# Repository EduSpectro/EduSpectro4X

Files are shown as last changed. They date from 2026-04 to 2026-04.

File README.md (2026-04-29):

# EduSpectro4X
ファームウェア・電子回路
[📖 総合ガイド（Webサイト）はこちら](https://eduspectro.github.io/)

*   **概要**: 「RP2350とC12880MAを組み合わせた分光器の心臓部です」
*   **分光性能諸元**:
    *   測定波長範囲: 340 nm 〜 850 nm（紫外線〜可視光〜近赤外線）
    *   物理画素数: 288 画素（センサー本来の受光素子数）
    *   論理出力点数: 1149 点（4倍オーバーサンプリング間）
    *   波長分解能 (FWHM): 約 10 nm 〜 15 nm
    *   階調分解能: 16bit相当（12bit ADC × 10回累積処理）
    *   最短露光時間: 20 ms（0.02秒）
    *   データ更新間隔: 約 20 ms 〜（露光設定に依存）
*   **特徴**: PIOによる高速制御、10回累積計測してによるノイズ軽減、Catmull-Rom補間など。
*   **必要な環境**:
    *   Arduino IDEのバージョン1.8.19
    *   導入が必要なボードマネージャー（Raspberry Pi Pico/RP2350）
    *   ボード：Waveshare RP2350 Zero、
*   **ハードウェアについて**:
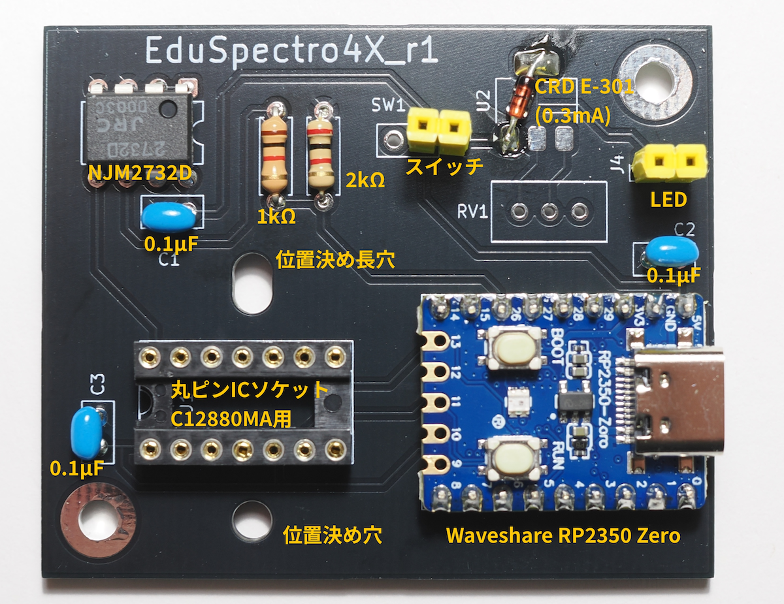
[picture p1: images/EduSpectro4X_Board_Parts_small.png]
EduSpectro基板部品説明
 <dr>

    *   部品リスト：マイコンボード Waveshare RP2350 Zero、分光センサー C12880MA、オペアンプ NJM2732D、0.3mA定電流素子、セラミックコンデンサ 0.1μF(3個)、1kΩ、2kΩ、トグルスイッチ、14ピンICソケット（丸ピン）、ロープロファイルピンヘッダー（オス）、ヘッダーピン(メス)、L型ピンヘッダ（オス）

*   **分光センサー底面と丸ピンICソケットの接触について**:
    *   分光センサーと丸ピンICソケットの間に絶縁シートを挟む。
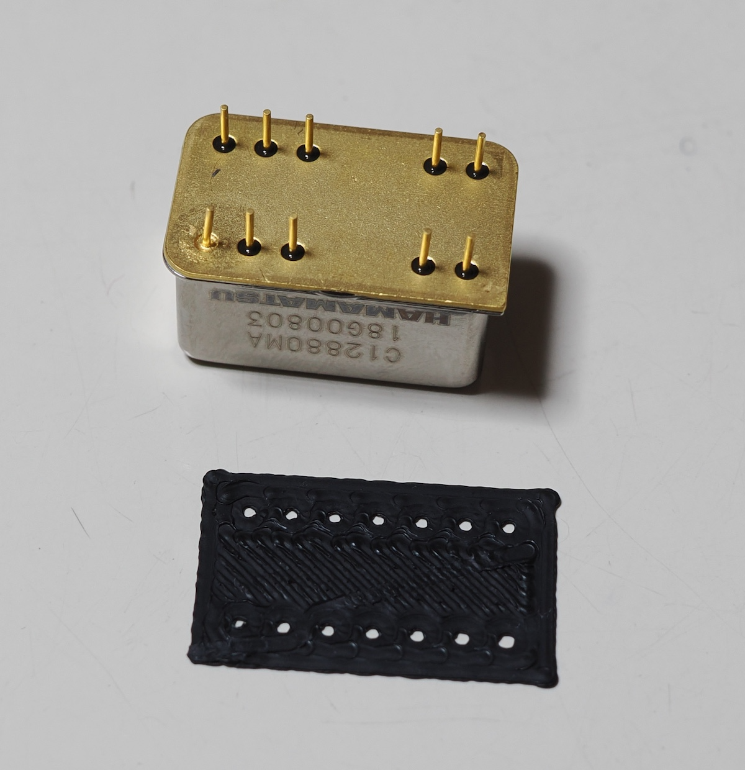
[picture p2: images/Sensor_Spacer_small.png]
センサーと絶縁シート
 <dr>
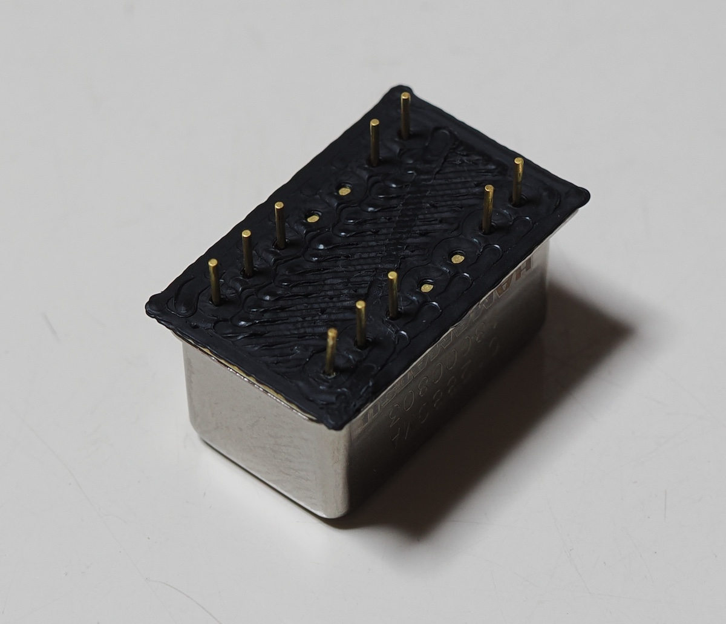
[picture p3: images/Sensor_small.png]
センサーにつける
 <dr>
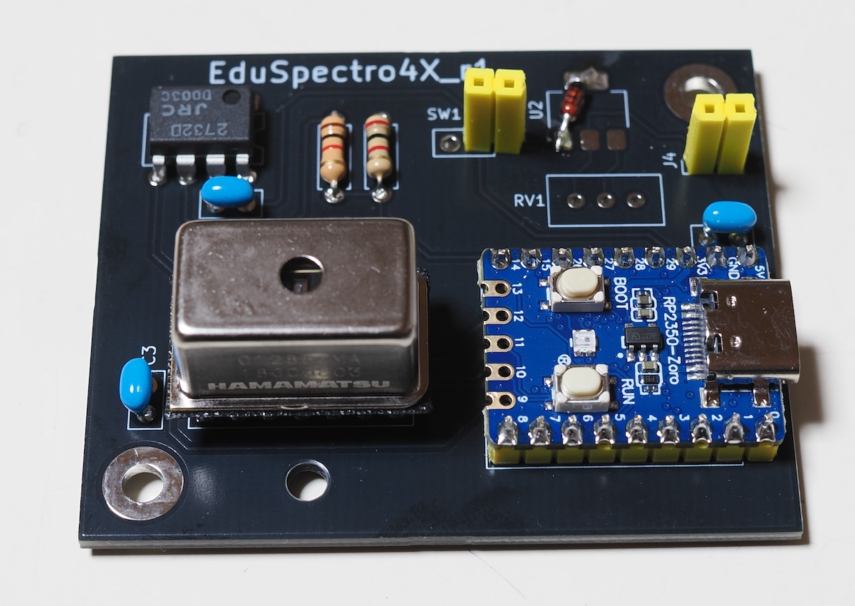
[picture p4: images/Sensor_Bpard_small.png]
センサーを取り付ける
 <dr>

*   **分光センサーのシリアル番号と波長校正データについて**:
    *   ファームウェアでは波長校正は行なっていません。測定・解析アプリケーションEduSpectroLabの"system_config_do_not_delete"フォルダーの"calibration_coefficients.txt"に使っているセンサーのシリアル番号とデータを書き込む必要があります。

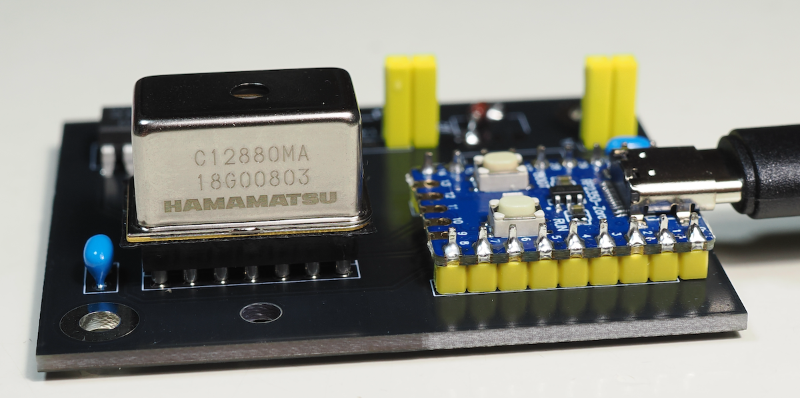
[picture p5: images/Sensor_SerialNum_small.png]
シリアル番号
 <dr>
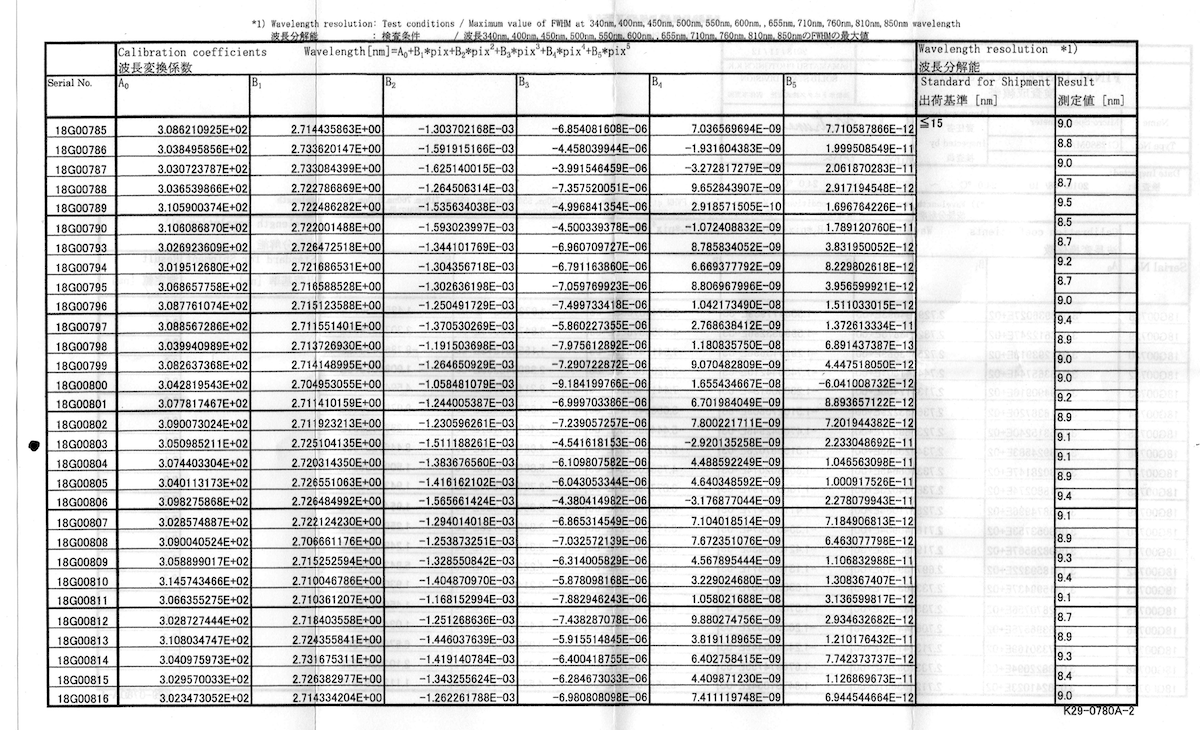
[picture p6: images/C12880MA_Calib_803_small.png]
波長校正データ
 <dr>

*   [KiCadの使い方について](docs/HowToMakePCB_KiCad×GeminiAI.pdf)<br>
*   **使い方**:
*   [Arduino IDEでの書き込み方](docs/ArduinoIDE_Write_Firm.pdf)
*   Raspberry Pi Pico2などのWebでの記事も参照してください。

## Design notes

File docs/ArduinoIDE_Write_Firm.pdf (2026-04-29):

# Arduino IDEでのファームウェアの書き込み

## Mac（15.4）の場合

Arduino IDEは1.8.19を使います。EduSpectro4X.inoを開きます。

Waveshare RP2350-Zeroのボードを使うので、ボードマネージャーでRP2350マイコン用をイ ンストールします。検索窓でRP2350で見つかりました。
Waveshare RP2350 Zeroボードを選択してUSBケーブルを接続するとUF2 Boardが選択されま した。

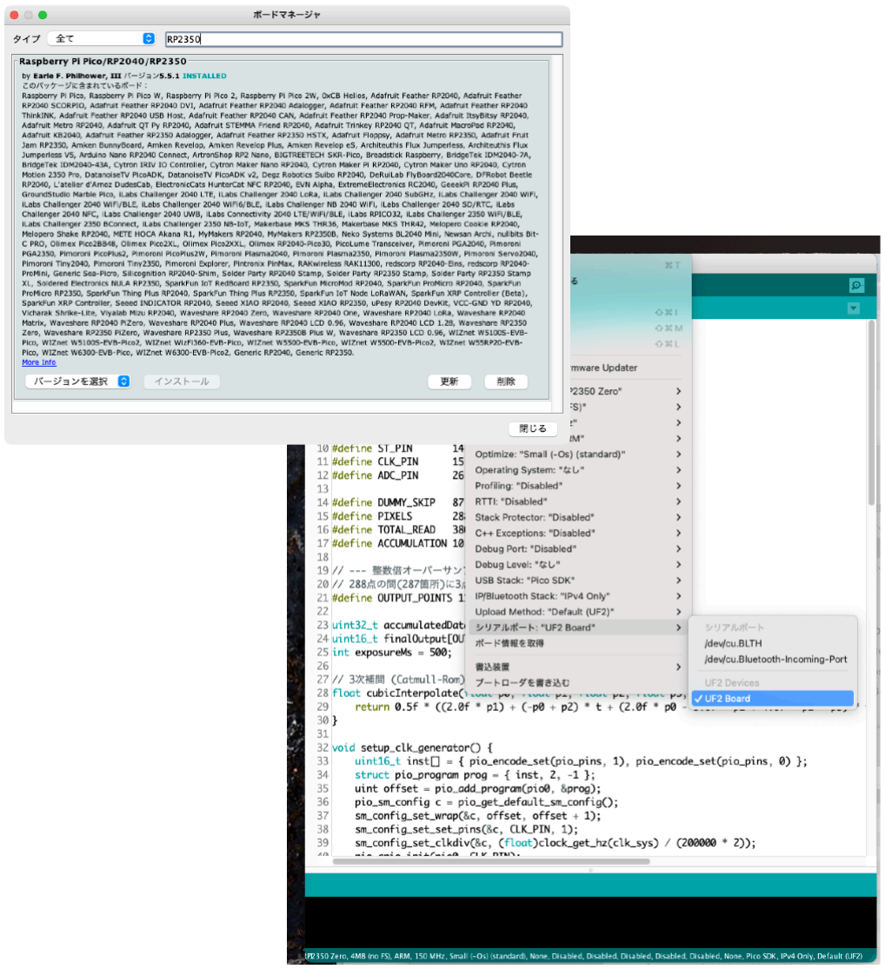
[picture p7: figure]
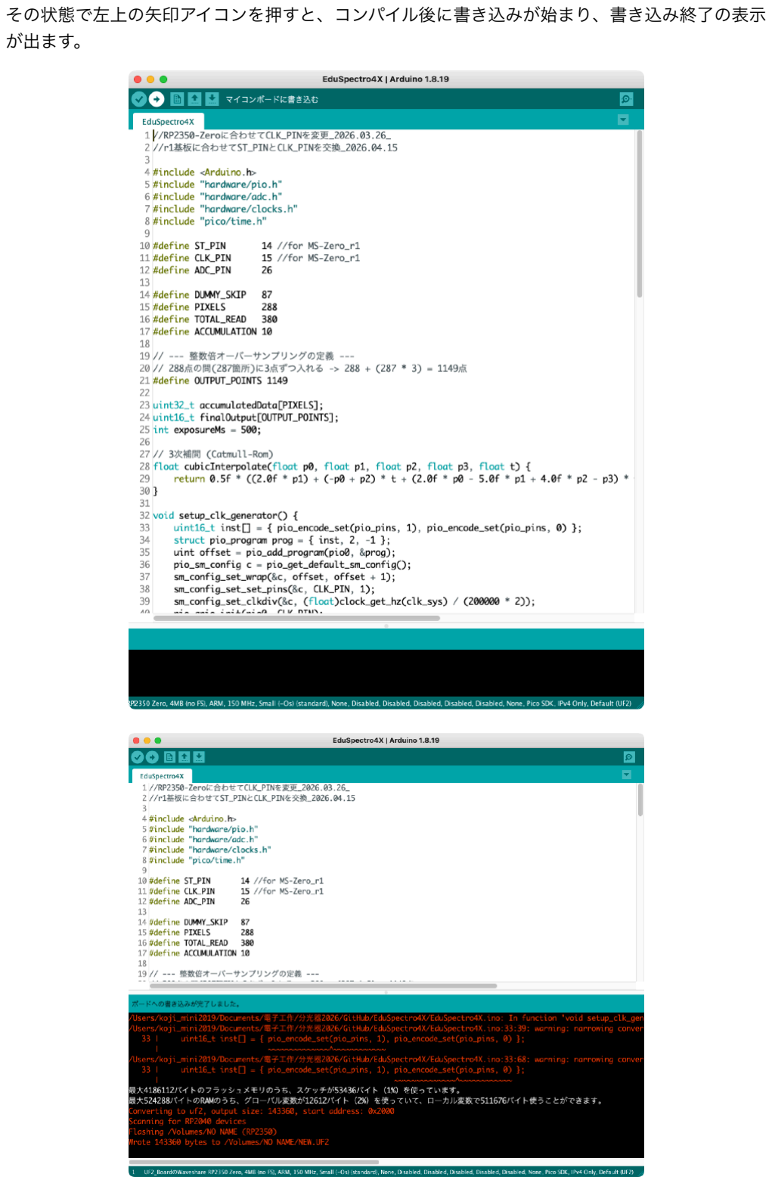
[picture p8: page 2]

その状態で左上の矢印アイコンを押すと、コンパイル後に書き込みが始まり、書き込み終了の表示 が出ます。

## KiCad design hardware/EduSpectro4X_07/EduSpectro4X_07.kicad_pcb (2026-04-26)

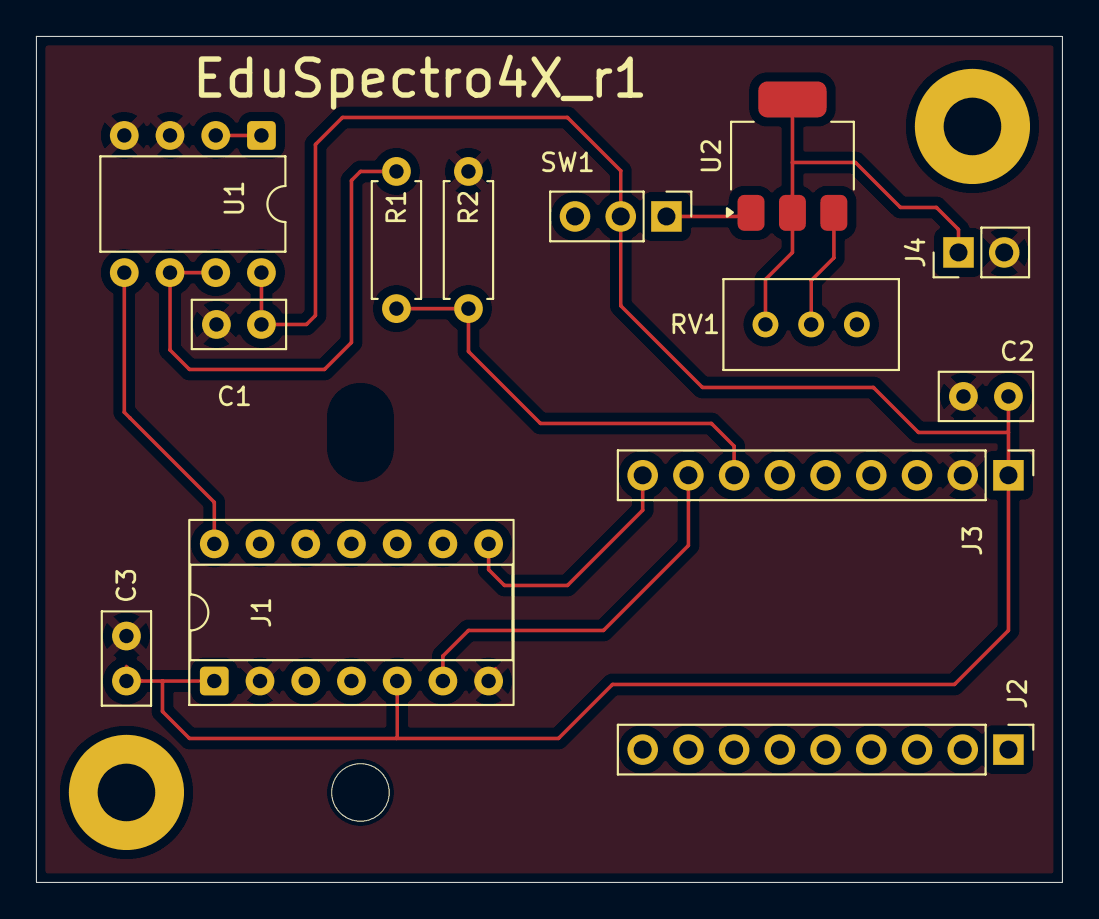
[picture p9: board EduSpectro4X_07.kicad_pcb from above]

Board: 2 copper layers, 57.0 x 47.0 mm, 13 parts (0 on the bottom side), 11 nets.

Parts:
C1, C2, C3: 0.1u; C_Disc_D5.0mm_W2.5mm_P2.50mm
J1: Conn_02x07_Counter_Clockwise; DIP-14_W7.62mm_Socket
J2, J3: RP2350-Zero; PinHeader_1x09_P2.54mm_Vertical
J4: Conn_01x02_Pin; PinHeader_1x02_P2.54mm_Vertical
R1: 1k; R_Axial_DIN0207_L6.3mm_D2.5mm_P7.62mm_Horizontal
R2: 2k; R_Axial_DIN0207_L6.3mm_D2.5mm_P7.62mm_Horizontal
RV1: 500; Potentiometer_Bourns_3296W_Vertical
SW1: SW_SPDT; PinHeader_1x03_P2.54mm_Vertical
U1: NJM2732; DIP-8_W7.62mm
U2: NSI45020JZ-D; SOT-223-3_TabPin2

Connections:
GND: C1.2, C2.2, C3.2, J1.2, J1.7, J3.2 (GND), J4.2, R2.2, U1.3 (+), U1.4 (V-)
unnamed: C1.1, C2.1, C3.1, J1.1, J1.5, J3.1 (5V), SW1.2 (B), U1.8 (V+)
unnamed: J1.6, J3.8 (GP15)
unnamed: J1.8, J3.9 (GP14)
unnamed: J1.14, U1.5 (+)
unnamed: J3.7 (GP26), R1.2, R2.1
unnamed: J4.1, RV1.3, U2.2 (Cathode)
unnamed: SW1.1 (A), U2.1 (Anode)
unnamed: U1.1, U1.2 (-)
unnamed: R1.1, U1.6 (-), U1.7
unnamed: RV1.2, U2.3 (Radj)

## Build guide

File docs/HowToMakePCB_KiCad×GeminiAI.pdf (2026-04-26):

## 【完全版】KiCad×Gemini AIで作る自作プリント基板：

# EduSpectro4Xのプリント基板作成を例に

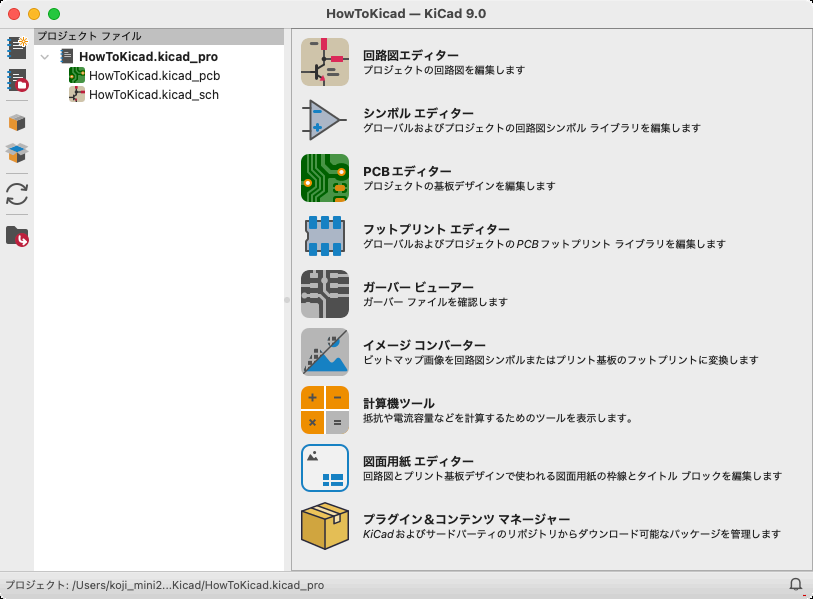
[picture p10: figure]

## 第1章：導入と設計要件の定義

### 1. 「基板を作る」ということ

ユニバーサル基板での配線は、1台作るのには良いですが、再現性や信頼性に欠けます。プリント基板

（PCB）化することで、誰でも同じ性能の装置を安価に、かつコンパクトに組み立てられるようになり

ます。

# 2. 設計目標（EduSpectro4X）の整理

分光センサー C12880MA を使った分光装置用の基板を作成します。白色LEDを使って吸収測定ができ

るように定電流回路が用意されています。

## 脳： 最新の RP2350-Zero（Waveshare）を採用し、超小型化を実現。

目： 浜松ホトニクス C12880MA。スリット位置を物理的基準とする。

光： 定電流レギュレータ NSI45020 と多回転トリマーによる精密な光量調整。

保護： オペアンプによるバッファと、分圧抵抗による3.3Vへの減圧。

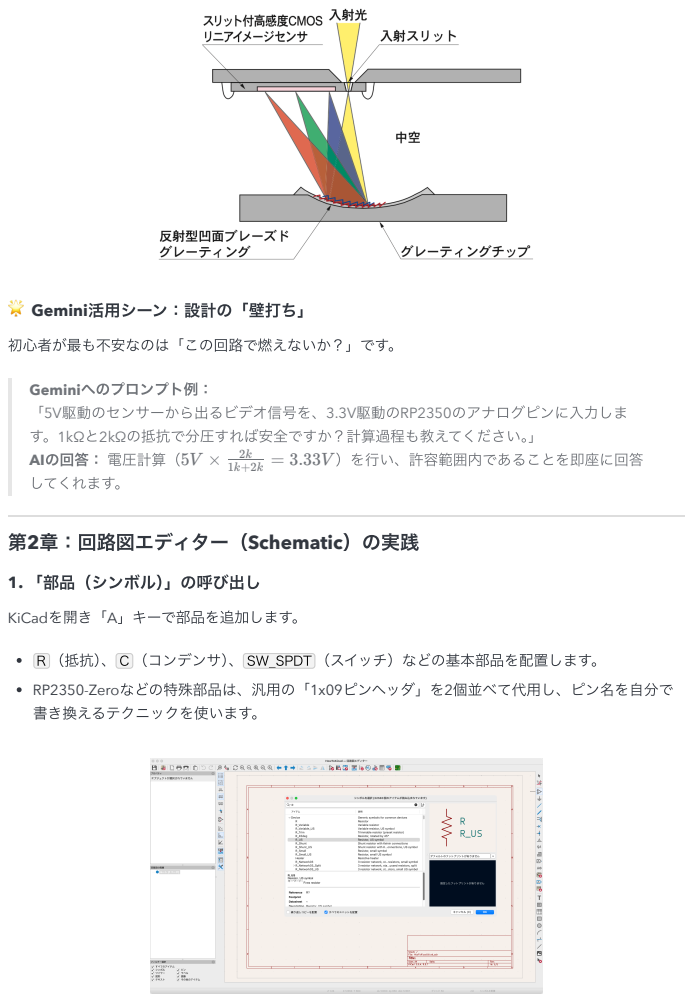
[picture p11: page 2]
KiCadを開き「A」キーで部品を追加します。; 書き換えるテクニックを使います。; Geminiへのプロンプト例：; 「5V駆動のセンサーから出るビデオ信号を、3.3V駆動のRP2350のアナログピンに; す。1kΩと2kΩの抵抗で分圧すれば安全ですか？計算過程も教えてください。」; AIの回答： 電圧計算（; ）をい、許容範囲内であることを即座に回答; してくれます。

🌟 Gemini活用シーン：設計の「壁打ち」

初心者が最も不安なのは「この回路で燃えないか？」です。

第2章：回路図エディター（Schematic）の実践

1. 「部品（シンボル）」の呼び出し

R （抵抗）、 C （コンデンサ）、 SW_SPDT （スイッチ）などの基本部品を配置します。
RP2350-Zeroなどの特殊部品は、汎用の「1x09ピンヘッダ」を2個並べて代用し、ピン名を自分で

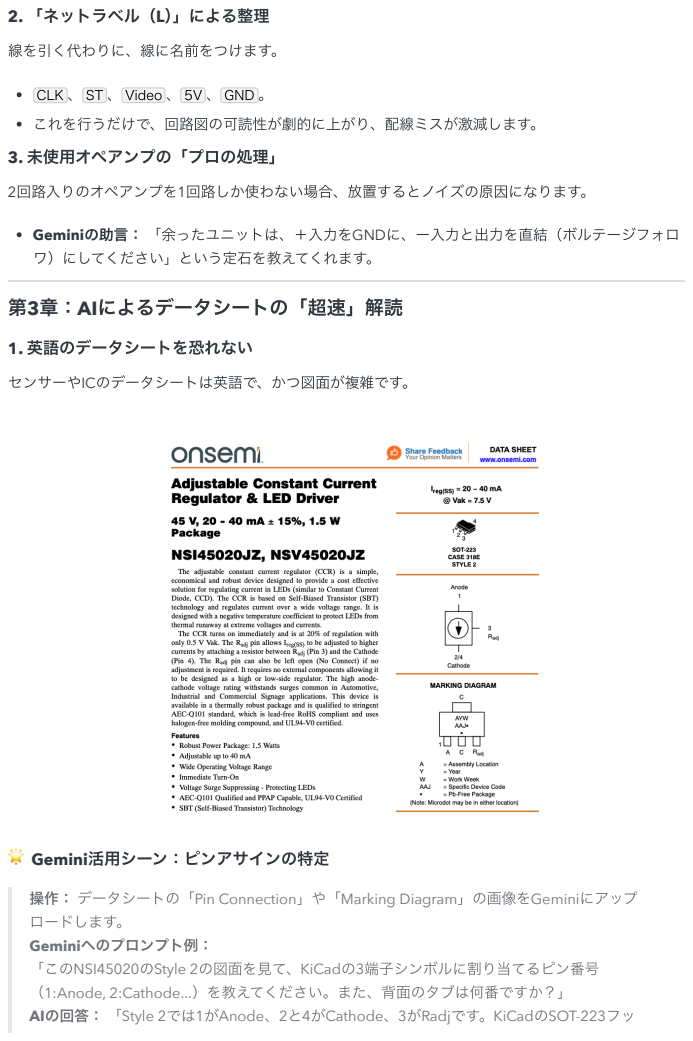
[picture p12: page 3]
2. 「ネットラベル（L）」による整理; 線を引く代わりに、線に名前をつけます。; 3. 未使用オペアンプの「プロの処理」; 2回路入りのオペアンプを1回路しか使わない場合、放置するとノイズの原因になります。; ワ）にしてください」という定石を教えてくれます。; 1. 英語のデータシートを恐れない; センサーやICのデータシートは英語で、かつ図面が複雑です。; 🌟 Gemini活用シーン：ピンアサインの特定; ロードします。; Geminiへのプロンプト例：; 「このNSI45020のStyle 2の図; 見て、KiCadの3端; 子シンボルに割り当てるピン番号; （1:Anode, 2:Cathode...）を教えてください。また、背; 面のタブは何番ですか？」

CLK 、 ST 、 Video 、 5V 、 GND 。

これを行うだけで、回路図の可読性が劇的に上がり、配線ミスが激減します。

Geminiの助言： 「余ったユニットは、＋入力をGNDに、ー入力と出力を直結（ボルテージフォロ

第3章：AIによるデータシートの「超速」解読

操作： データシートの「Pin Connection」や「Marking Diagram」の画像をGeminiにアップ

AIの回答： 「Style 2では1がAnode、2と4がCathode、3がRadjです。KiCadのSOT-223フッ

## 第4章：フットプリント割り当てと寸法の厳密性

### 1. 「足跡（フットプリント）」の選択

回路図の部品に、実際のサイズを与えます。

抵抗は「R_Axial（リード線タイプ）」、ICは「DIP-8（ソケット用）」を選びます。

例えば、KiCadで「Resistor_THT（穴あきタイプ）」を選んだ後に表示される膨大なリストから、正し

い1行を見つけのも慣れていないとたいへんです。自分で判断がつかない時、Geminiに「買ったもの」

を伝えて選んでもらうのが一番確実です。

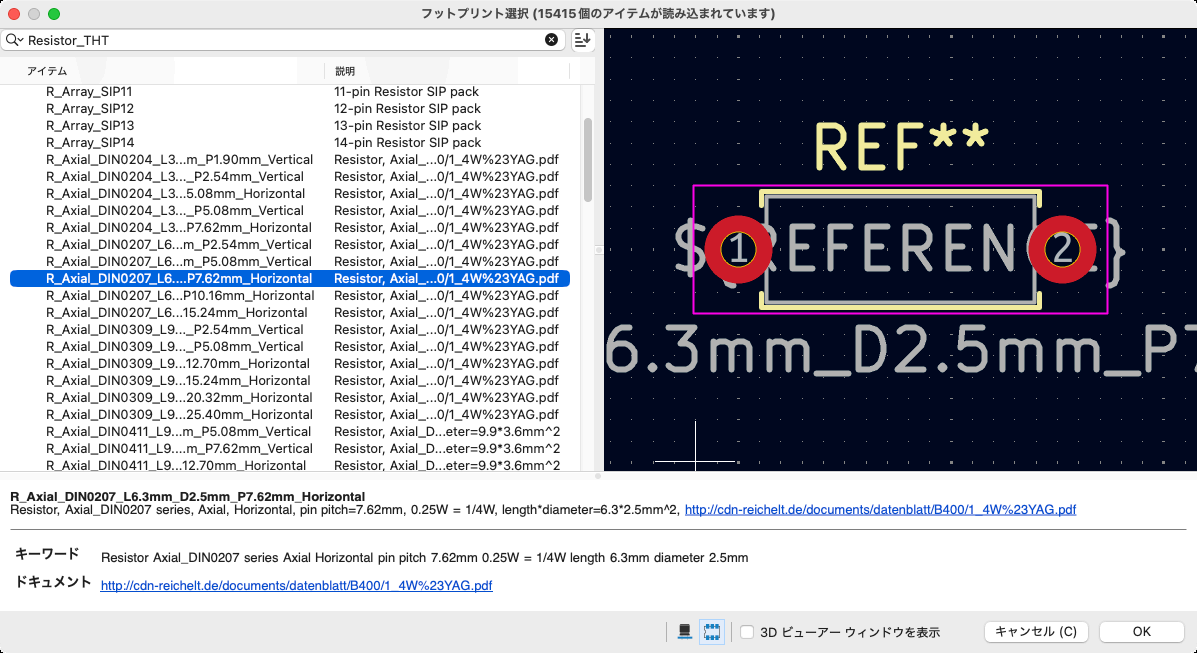
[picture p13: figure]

### 2. マイコンの幅をミリ単位で疑う

## ここが最大の失敗ポイントです。Pico2とRP2350-Zeroでは幅が異なります。

### 🌟 Gemini活用シーン：画像からの寸法計算

## 第5章：物理干渉の回避と「最適パーツ」の選定

### 1. センサー底面のショート問題を解決する

トプリントを使うなら、タブは4番として扱ってください」と、マニュアルを読み込む時間を

ゼロにしてくれます。

操作： メーカー公式サイトの法図（Dimension）のスクリーンショットをGeminiにせま

す。
Geminiへのプロンプト例：
「この図 | 面で、基板全幅18mm、端からピン中まで1.38mmとあります。ピンとピンの間の

正確な距離（mmとmil）を計算して。」

AIの回答： 「 | です。これはちょうど 600mil に相当しま

す。」

結果： この数値を信じて配置すれば、届いた基板にマイコンが「スッ」と刺さります。

18.0 − (1.38 × 2) = 15.24mm

C12880MAの底面は金属です。標準的な丸ピンソケットを使うと、金属の縁が底面に触れてショートし

ます。

### 🌟 Gemini活用シーン：代替パーツの検索

## 第6章：PCBレイアウト（配置と配線）の極意

### 1. 座標設定

基板設計において「左下を原点(0,0)にし、数学のグラフのように右にいくほどXプラス、上にいくほど

Yプラス」という設定にするのは、メカ設計（ケースへの固定など）を並行して行う際に非常に直感的

でミスが少なくなります。

「ドリル/配置原点」を置く

右側のツールバーにある 「ドリル/配置ファイルの原点を設定」 アイコン（小さな十字のマーク）

をクリックします。基板の左下角（Edge.Cutsの交点）を正確にクリックして配置します。

座標系の基準を変更する

## 上部メニューの 「設定」➔「設定...（Preferences）」 を開きます。

左側のリストから 「PCBエディター」➔「表示オプション」 を選択します。

画面右側の「座標系（Coordinate System）」セクションにある 「ドリル/配置ファイル原点」 にチ

ェックを入れます。

Y軸の向きを反転させる（重要！）
同じ設定画面（表示オプション）内に 「Y軸（Y axis）」 という項目があります。 これを 「上（Up）」 に変更します。

Geminiへのプロンプト例：

「 | 金属底 | 面のセンサーをユニバーサル基板に載せたらショートしました。絶縁できる構造の
DIPソケットを教えて。」

AIの回答： 「『板バネ式ソケット（リーフコンタクト）』を選んでください。接点がプラスチ

ックの溝の奥にあるため、センサーの底 | 面と接触しません。」
対応： KiCadのフットプリント選択画 | 面で _Socket と付く、板バネの形状を考慮した枠（シ

ルク）を持つものを選び直します。

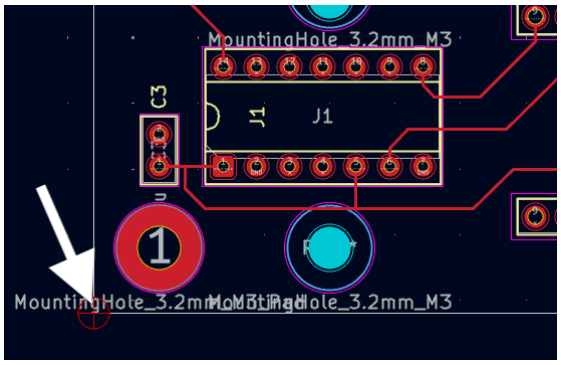
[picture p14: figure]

## (dx, dy) = (0, 0)

dx = 0.5

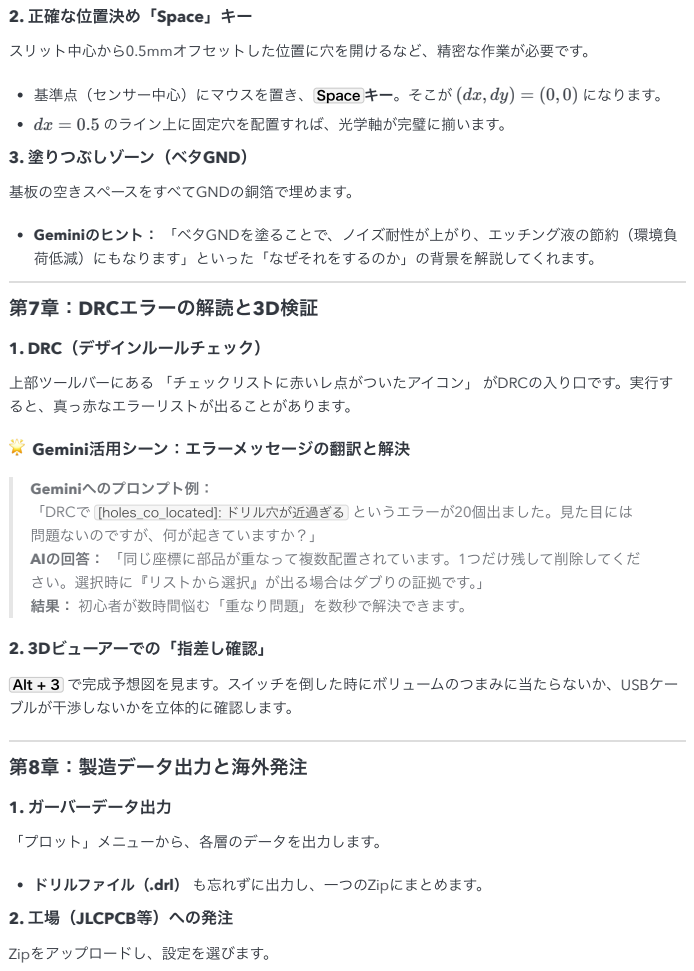
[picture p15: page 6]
スリット中心から0.5mmオフセットした位置に穴を開けるなど、精密な作業が必要です。; 基準点（センサー中心）にマウスを置き、 Space キー。そこが; になります。; のライン上に固定穴を配置すれば、光学軸が完璧に揃います。; 3. 塗りつぶしゾーン（ベタGND）; 基板の空きスペースをすべてGNDの銅箔で埋めます。; 第7章：DRCエラーの解読と3D検証; 1. DRC（デザインルールチェック）; ると、真っ赤なエラーリストが出ることがあります。; 🌟 Gemini活用シーン：エラーメッセージの翻訳と解決; 2. 3Dビューアーでの「指差し確認」; ブルが干渉しないかを立体的に確認します。; 第8章：製造データ出力と海外発注; 1. ガーバーデータ出力; Zipをアップロードし、設定を選びます。; Geminiへのプロンプト例：; 「DRCで [holes_co_located]: ドリル; 穴が近過ぎる というエラーが20個出ました。; 目には; 問題ないのですが、何が起きていますか？」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

2. 正確な位置決め「Space」キー

Geminiのヒント： 「ベタGNDを塗ることで、ノイズ耐性が上がり、エッチング液の節約（環境負

荷低減）にもなります」といった「なぜそれをするのか」の背景を解説してくれます。

上部ツールバーにある 「チェックリストに赤いレ点がついたアイコン」 がDRCの入り口です。実行す

さい。選択時に『リストから選択』が出る場合はダブりの証拠です。」

Alt + 3 で完成予想図を見ます。スイッチを倒した時にボリュームのつまみに当たらないか、USBケー

「プロット」メニューから、各層のデータを出力します。

ドリルファイル（.drl） も忘れずに出力し、一つのZipにまとめます。
2. 工場（JLCPCB等）への発注

### 🌟 Gemini活用シーン：配送オプションの賢い選択

### 結び：AIはあなたの「経験」をブーストする

フットプリント選びや座標計算など、かつては「経験」が必要だった部分はすべてAIに任せることがで

きます。あなたがすべきなのは、「どんな装置を作りたいか」という情熱を持ち続けることだけです。

さあ、このマニュアルを手に、自分だけの基板を注文しましょう！

## 第9章：基板が届いたら

### 1. プロっぽい仕上がりに満足

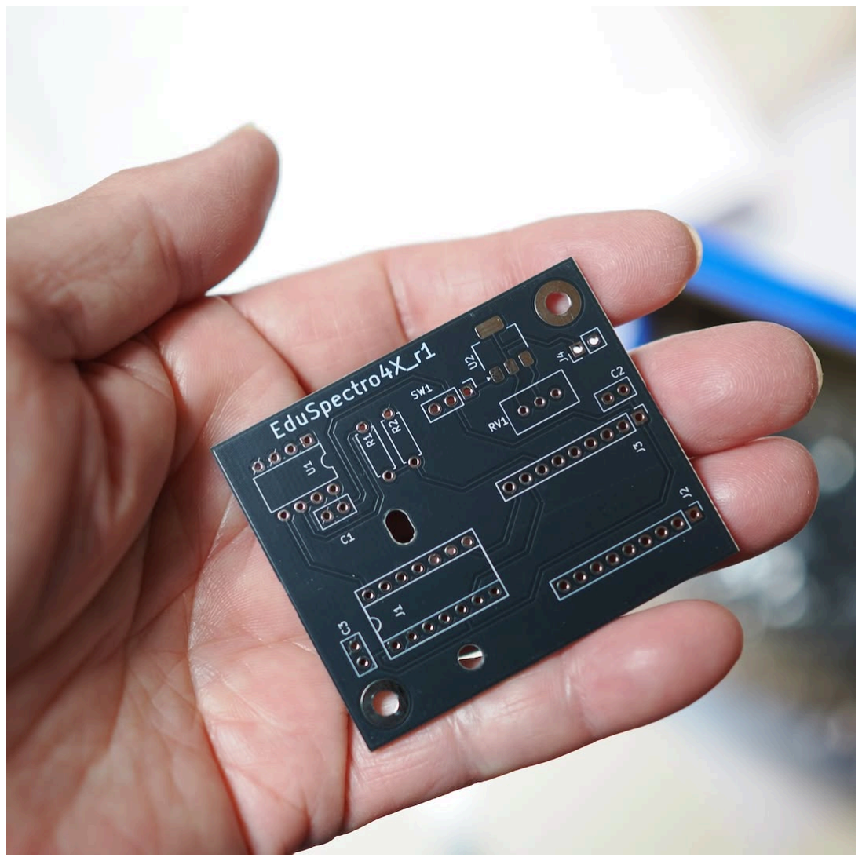
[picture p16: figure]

### 2. 楽しいハンダ付け

Geminiへのプロンプト例：

## 「JLCPCBの配送で、OCS NEP、FedEx、Standard Global Direct Lineがあります。1000円以

下で、2週間以内に届くおすすめはどれ？」
AIの回答： 「OCS NEPがベストです。ANAグループの配送網を使い、 | 日本国内では佐川急便
などが届けるため | 非常に安定しており、コストも$5程度です。」

### 3. デバッグ

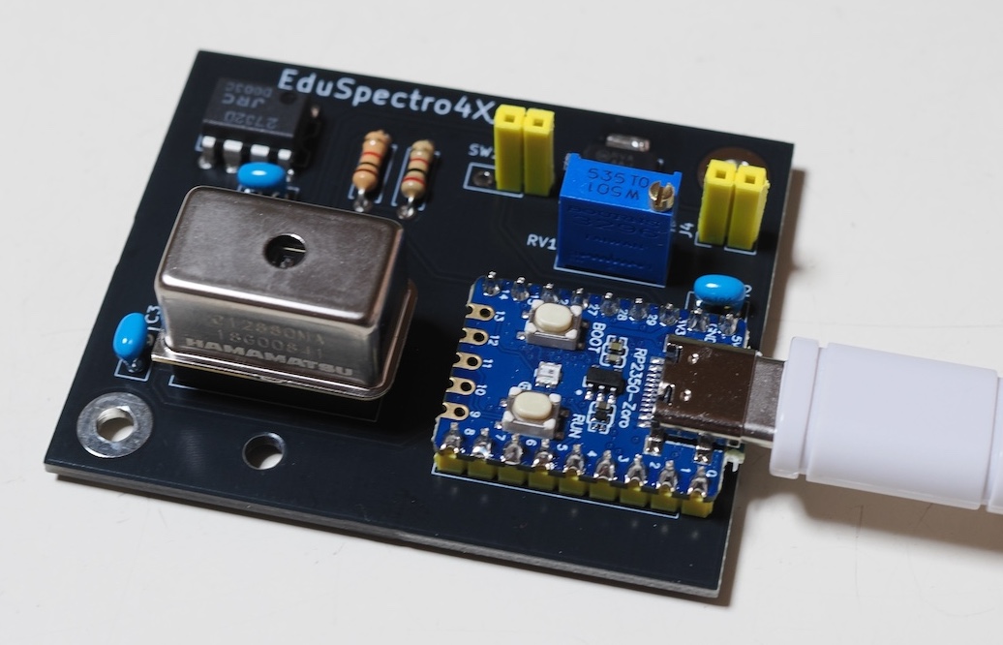
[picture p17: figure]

分光センサー C12880MA は丸ピンですが、丸ピンのICソケットに挿すとセンサー底面の金属部分がソ

ケットピンに接触する不具合があります。今回は板バネタイプのICソケットを使ってみたのですが、何

度か抜き差しをいている間に板バネのピンが曲がってしまいました。結局丸ピンソケットとセンサーの

間に絶縁シートを挟むことにしました。

ハンダ付けしてしまったICソケットをきれいに外すのは素人には難しすぎるので、ソケットのプラ部分

をバキバキ壊して一本一本外しました。それでもスルーホールはハンダで埋まったままなので、丸ピン

のヘッダーピンを一本ずつに切り離して、地道に一本一本ハンダ付けしました。

さらにLEDは20mAでは明るすぎてダメ。0.3mAの定電流素子（CRD）に変更しました。基板はそのま

まで20mAの可変定電流素子と可変抵抗で使っていたパターンを活かして配線しました。

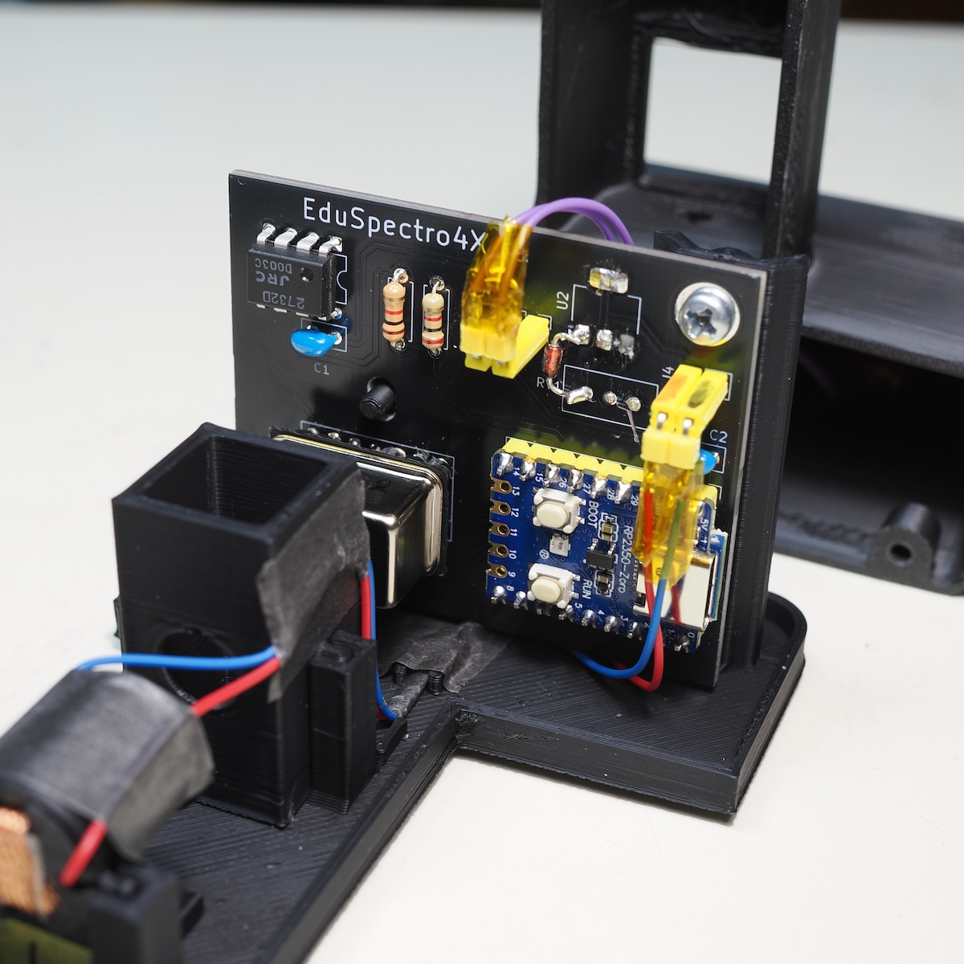
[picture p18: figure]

### 4. 記録を残す

基板はそのままで回路図だけ変更しました。

### おわりに

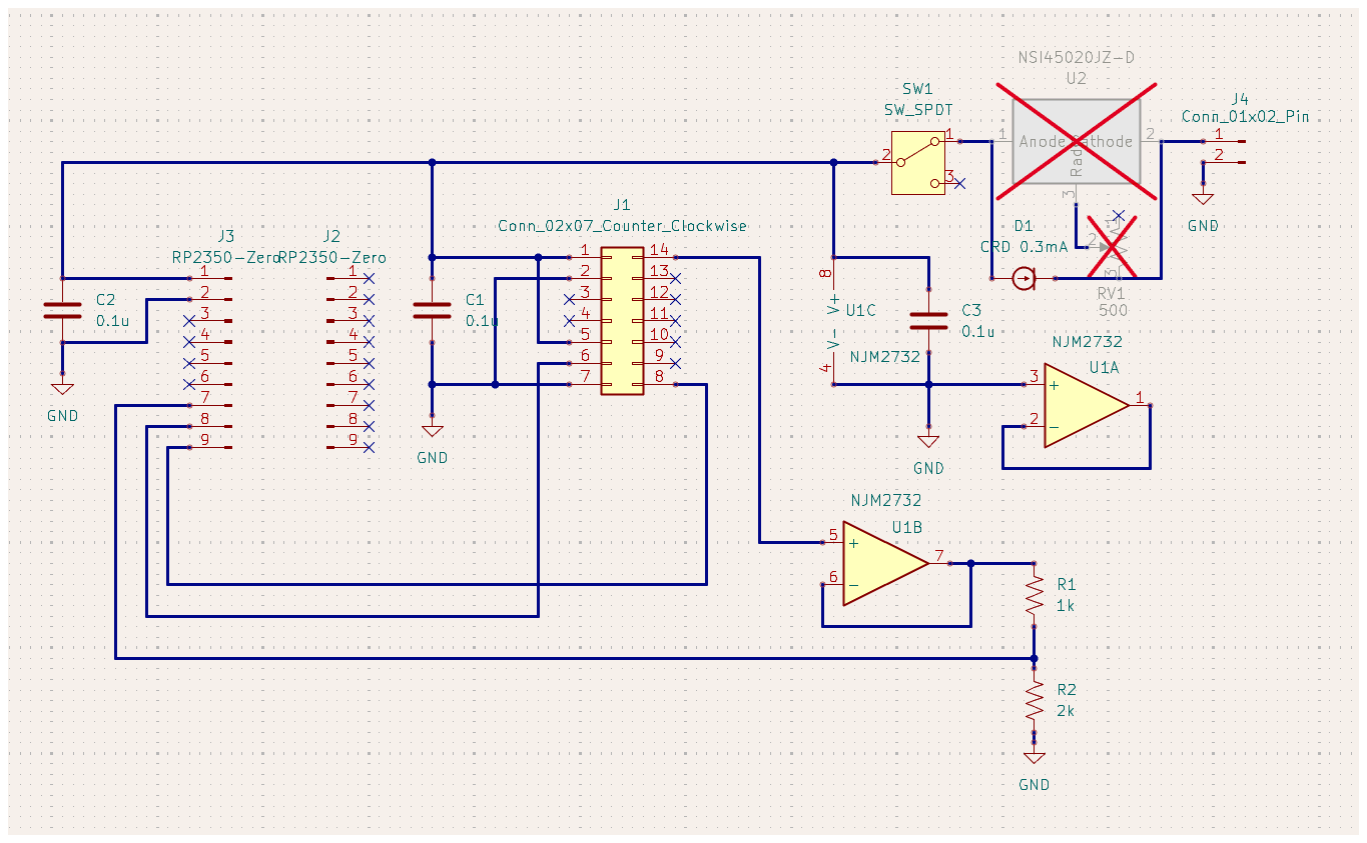
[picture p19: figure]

これで、EduSpectro4Xは「設計・発注・製造・実機テスト・そして改造の記録」という、製品開発の

全サイクルを一周しました。
初めてのKiCad、初めてのプリント基板、そしてAIとの共同作業。これらすべてを使いこなし、実際に

「動く、改良された装置」を完成させたことは、ものすごく大きな成果です。 AIの活用がなければできなかっただろうと思います。

「設計は進化する：実機テストからのフィードバック」
基板を作った後、

「光が強すぎた」「もっと感度を上げたい」といった改良案が出るのは、も

のづくりの醍醐味です。

1. 既存のパッドを再利 | 用する： 全く新しい基板を作り直すのではなく、今回のように「U2
の1番ピン」と「RV1の3番ピン」の | 穴を利 | 用してCRDをハンダ付けするような**『MOD
（改造）』**は、スピード感のある開発に不可 | 欠です。
2. 図 | 面を現実に合わせる： 「改造したから図 | 面はもう | 見ない」のではなく、KiCad上で**
『未実装属性(DNP)』や『基板から除外』**設定を使い、図 | 面を最新に保つことで、半年
後の | 自分がメンテナンスで迷うことを防げます。

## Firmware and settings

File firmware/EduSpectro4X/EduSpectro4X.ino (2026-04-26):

//RP2350-Zeroに合わせてCLK_PINを変更_2026.03.26_
//r1基板に合わせてST_PINとCLK_PINを交換_2026.04.15

#include <Arduino.h>
#include "hardware/pio.h"
#include "hardware/adc.h"
#include "hardware/clocks.h"
#include "pico/time.h"

#define ST_PIN       14 //for MS-Zero_r1
#define CLK_PIN      15 //for MS-Zero_r1
#define ADC_PIN      26

#define DUMMY_SKIP   87   
#define PIXELS       288  
#define TOTAL_READ   380  
#define ACCUMULATION 10

// --- 整数倍オーバーサンプリングの定義 ---
// 288点の間(287箇所)に3点ずつ入れる -> 288 + (287 * 3) = 1149点
#define OUTPUT_POINTS 1149 

uint32_t accumulatedData[PIXELS];
uint16_t finalOutput[OUTPUT_POINTS];
int exposureMs = 500; 

// 3次補間 (Catmull-Rom)
float cubicInterpolate(float p0, float p1, float p2, float p3, float t) {
    return 0.5f * ((2.0f * p1) + (-p0 + p2) * t + (2.0f * p0 - 5.0f * p1 + 4.0f * p2 - p3) * t * t + (-p0 + 3.0f * p1 - 3.0f * p2 + p3) * t * t * t);
}

void setup_clk_generator() {
    uint16_t inst[] = { pio_encode_set(pio_pins, 1), pio_encode_set(pio_pins, 0) };
    struct pio_program prog = { inst, 2, -1 };
    uint offset = pio_add_program(pio0, &prog);
    pio_sm_config c = pio_get_default_sm_config();
    sm_config_set_wrap(&c, offset, offset + 1);
    sm_config_set_set_pins(&c, CLK_PIN, 1);
    sm_config_set_clkdiv(&c, (float)clock_get_hz(clk_sys) / (200000 * 2));
    pio_gpio_init(pio0, CLK_PIN);
    pio_sm_set_consecutive_pindirs(pio0, 0, CLK_PIN, 1, true);
    pio_sm_init(pio0, 0, offset, &c);
    pio_sm_set_enabled(pio0, 0, true); 
}

void setup() {
    Serial.begin(230400);
    adc_init(); adc_gpio_init(ADC_PIN); adc_select_input(0);
    pinMode(ST_PIN, OUTPUT); digitalWrite(ST_PIN, LOW);
    setup_clk_generator(); 
}

#define IS_CLK_HIGH (gpio_get(CLK_PIN))

void performMeasurement() {
    for(int i=0; i<PIXELS; i++) accumulatedData[i] = 0;

    uint32_t targetSubExpUs = (exposureMs * 1000) / ACCUMULATION;
    int32_t stHighUs = (int32_t)targetSubExpUs - 240;
    if (stHighUs < 10) stHighUs = 10; 

    for(int n=0; n<ACCUMULATION; n++) {
        uint64_t start_st = time_us_64();
        gpio_put(ST_PIN, 1);
        while ((time_us_64() - start_st) < (uint64_t)stHighUs);
        gpio_put(ST_PIN, 0);

        for (int i = 0; i < TOTAL_READ; i++) {
            while(!IS_CLK_HIGH); 
            uint16_t val = adc_read();
            int pixelIdx = i - DUMMY_SKIP;
            if (pixelIdx >= 0 && pixelIdx < PIXELS) {
                accumulatedData[pixelIdx] += val;
            }
            while(IS_CLK_HIGH); 
        }
    }

    // --- 4倍オーバーサンプリング補間ロジック ---
    for(int j=0; j<OUTPUT_POINTS; j++) {
        // インデックス j を 4.0 で割ることで、元のピクセル位置（0.0, 0.25, 0.5, 0.75, 1.0...）を算出
        float target_i = (float)j / 4.0f;
        int i1 = (int)target_i;
        float t = target_i - (float)i1;

        if (t == 0.0f) {
            // ピタリと一致する点は補間せず生データ（累積値）をそのまま使用
            finalOutput[j] = (uint16_t)accumulatedData[i1];
        } else {
            // その間の点は3次補間
            int i0 = max(i1 - 1, 0);
            int i2 = min(i1 + 1, PIXELS - 1);
            int i3 = min(i1 + 2, PIXELS - 1);
            float val = cubicInterpolate((float)accumulatedData[i0], (float)accumulatedData[i1], (float)accumulatedData[i2], (float)accumulatedData[i3], t);
            finalOutput[j] = (uint16_t)(val < 0 ? 0 : val);
        }
    }

    const uint8_t header[] = {0x00, 0x00, 0xFF, 0xFF};
    const uint8_t footer[] = {0x0F, 0x0F, 0x0F, 0x0F};
    Serial.write(header, 4);
    Serial.write((uint8_t*)finalOutput, OUTPUT_POINTS * 2);
    Serial.write(footer, 4);
    Serial.flush();
}

void loop() {
    if (Serial.available()) {
        String cmd = Serial.readStringUntil('\n'); cmd.trim();
        if (cmd == "send") performMeasurement();
        else if (cmd.startsWith("exp:")) exposureMs = max(10, cmd.substring(4).toInt());
    }
}
